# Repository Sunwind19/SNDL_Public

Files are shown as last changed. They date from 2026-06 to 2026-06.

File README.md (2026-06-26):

# SNDL
This is repository for SNDL, a biomimetic robot that is your unique companion for your climate action. When you pick up, SNDL carries! 

## Project Introduction




This is SNDL, a waste collecting beetle-like 6-legged biomimetic robot companion, building a sustainable future through protecting nature closest to our daily life. 

SNDL revolutionize this reality through first-ever innovation inspired by insects’ skeletal structures evolved to survive in harsh terrains. Built over believing “nature already holds the answer to our problem”, SNDL targets to remove all the accumulated trash through collaboration with human. No need to carry heavy wastes and get exhausted over exhausted: you can just hand them in to SNDL and it’ll carry it for you!

By mimicking the Diabolical Ironclad Beetle and the Metallifer Stag Beetle, SNDL plan to restore one mountain ecosystem — one BIOME — proving we aren’t late to save this planet.

## Zine page


## BOM
The key parts here were
-2 PCA boards
-1 ESP Devkit V4
-18 MG90S motors
-20A DC-DC & 2A Dual Buck converter system
-15A & 3A Dual buck system
You can check out the details in BOM (Bill of Materials for SNDL).csv file and get the materials, and follow the schematics.pdf file! Soldering is fine, but I recommend using wago connectors at the beginning since theres high chance motor might burn for beginners. 

## Key CAD file
The most important design choice I made was to mimic insects' exoskeleton into the robot's main frame, so that it can carry a load of waste at once and be perfect companion for your waste-collecting journey. Specifically, SNDL can endure 4900x of its body weight because of its suture! As shown in assembly body.f3z / .step file, this exoskeleton is covered by shell, where body-coxa bracket, bearing bracket, femur and tibia are attached. 

## Firmware
The firmware has inverse kinematics & tripod gait feature.
You can connect your nintendo joycon or any other controller bluepad32 supports!

## Why?
The precious mountains where I once shared precious memories are now covered with waste. Just like scenary in WALL-E. Why? Because we couldn't collect them again unlike when we spreaded them out. Here, I wanted to bring robotic system to foster climate action and prove its not too late.

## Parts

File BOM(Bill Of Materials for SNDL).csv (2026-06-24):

Material name | Number | Total Price for parts(USD) | Link
MG90s 180 degree Motor | 18 | 24.66 | https://www.coupang.com/vp/products/8331026680?itemId=24052890806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
PCA9685 | 2 | 6.44 | https://www.coupang.com/vp/products/1137724853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
ESP32 DevkitC V4 | 1 | 10.24 | https://www.coupang.com/vp/products/8757170787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
18650 Battery (3000mAh, 3.7V) | 4 | 8.44 | https://www.coupang.com/vp/products/5032842187?itemId=25081547722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
18650 Battery Holder (4p) | 1 | 0.56 | https://www.coupang.com/vp/products/7397864403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
DT-830LN Multimeter | 1 | 5.15 | https://www.coupang.com/vp/products/8176825077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
Bulk Capacitor (4700uF, 50V) | 1 | 1.06 | https://www.coupang.com/vp/products/1065561592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
Ceramic Capacitor (0.01uF,50V) | 4 | 0.16 | https://www.coupang.com/vp/products/8540238444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
Fuse for vehicles (3A) | 10 | 1.45 | https://www.coupang.com/vp/products/9497182652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
Fuse for vehicles (15A) | 2 | 0.05 | https://www.coupang.com/vp/products/9195985582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
Fuse holder (5A) | 10 | 7.81 | https://www.coupang.com/vp/products/8511316183?itemId=24637065051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
Fuse holder (20A) | 10 | 9.7 | https://www.coupang.com/vp/products/8511316183?itemId=24637065051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
Flat head screw (M2,10mm) | 36 | 0.95 | https://www.coupang.com/vp/products/6168689383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
Flat head screw (M3,10mm) | 32 | 0.85 | https://www.coupang.com/vp/products/9081428280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
Flat head screw (M3,20mm) | 40 | 1.59 | https://www.coupang.com/vp/products/9081428280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
Hex Nut (M2, 1.5mm) | 36 | 1.19 | https://www.coupang.com/vp/products/8732352217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
Hex Nut (M3, 2.5mm) | 82 | 2.38 | https://www.coupang.com/vp/products/8732352217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
MR84ZZ Bearing | 18 | 3.09 | https://www.coupang.com/vp/products/5448395078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
Standoff (M3,25mm) | 20 | 4.62 | https://www.coupang.com/vp/products/8695499113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
XL4015 DC-DC Stepdown Converter (2A) | 1 | 2.67 | https://www.coupang.com/vp/products/5354288472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
DC-DC Stepdown Converter (300W, 20A) | 1 | 4.62 | https://www.coupang.com/vp/products/9127141798?itemId=26852534394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
221-413 Wago Connector 3p | 50 | 13.87 | https://www.coupang.com/vp/products/7599905141?itemId=7995179122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
221-415 Wago Connector 5p | 5 | 2.28 | https://www.coupang.com/vp/products/8844622739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
Silicon Cable Red & Black 1M (16AWG) | 1 | 0.87 | https://www.coupang.com/vp/products/7225302003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
Silicon Cable Red & Black 1M (22AWG) | 1 | 0.39 | https://www.coupang.com/vp/products/8230958366?itemId=23689081947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
15SQ045 Schottky diode (15A) | 1 | 0.3 | https://www.coupang.com/vp/products/208012195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
F-F Jumper Cable (20cm) | 40 | 0.99 | https://www.coupang.com/vp/products/9066477738?itemId=26624930723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
Total |  | 115.19

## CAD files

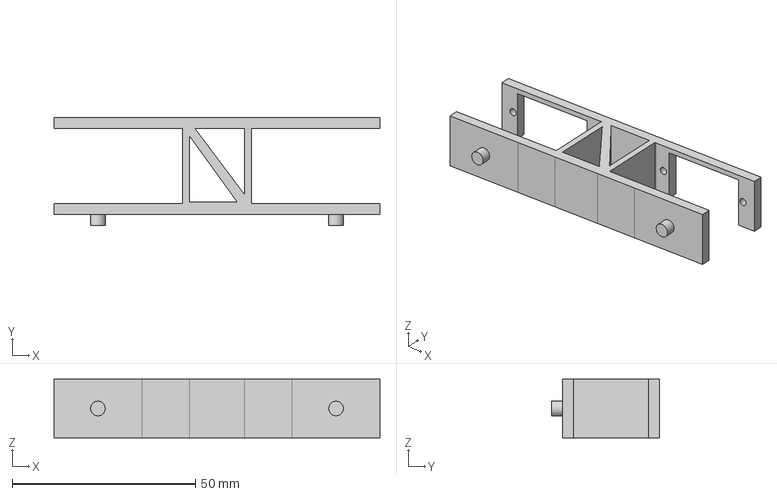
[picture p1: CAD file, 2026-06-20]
CAD files/Femur.step
89.0 x 29.4 x 16.0 mm

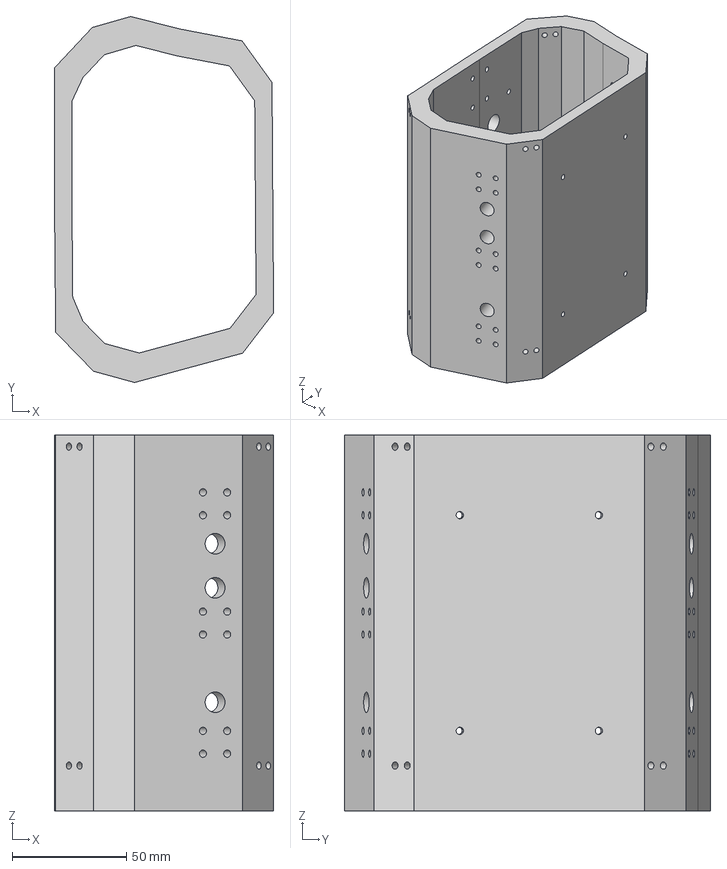
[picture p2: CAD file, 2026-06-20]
CAD files/Exoskeleton Ext.step
95.9 x 160.2 x 164.4 mm

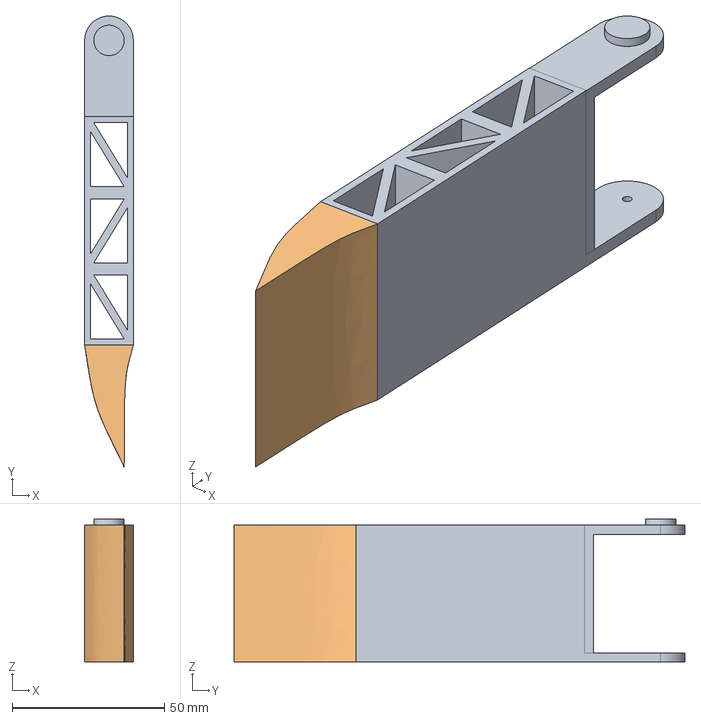
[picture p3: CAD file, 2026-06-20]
CAD files/bearing.step
16.0 x 148.0 x 46.9 mm

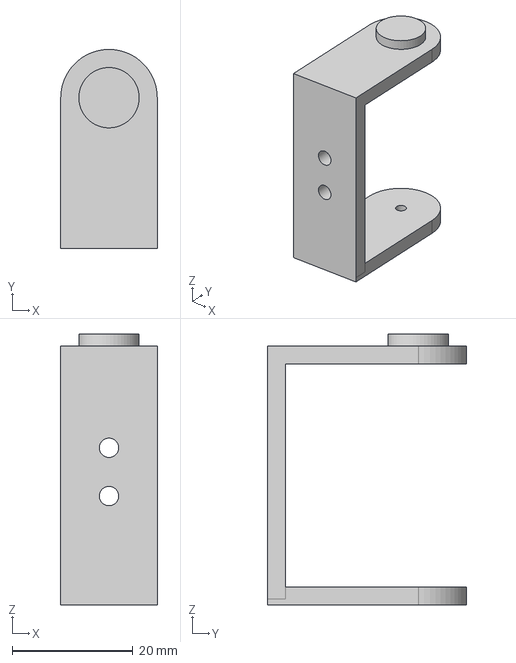
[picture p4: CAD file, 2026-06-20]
CAD files/2nd bearing.step
16.0 x 33.0 x 44.9 mm

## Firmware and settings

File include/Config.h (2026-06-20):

#include "Robot.h"

#include <Arduino.h>
#include "Config.h"
#include "Gait.h"
#include "Hardware.h"
#include "RobotState.h"
#include "StatusLed.h"
#include "ControllerInput.h"

namespace hexabot {

static unsigned long previousFrameTime = 0;
static unsigned long bootStartTime = 0;
static int bootStage = 0;
static bool hardwareInitialized = false;

// ============================================
// SAFE BOOT SEQUENCE (NO BLOCKING I2C IN SETUP)
// ============================================

void setupRobot() {
    Serial.begin(115200);
    delay(500);
    
    Serial.println("\n[BOOT] Starting hexabot initialization...");
    
    // Phase 1: GPIO-only operations (no I2C)
    initializeStatusLed();
    setStatusLed(true);  // Status LED ON during boot
    
    // Do NOT initialize PCA9685 here!
    // Do NOT call Wire.begin() here!
    // Do NOT set Wire.setTimeOut() here!
    
    // Phase 2: Initialize global state
    mode = RobotMode::Waiting;
    resetMotionCommands();
    resetBodyAttitude();
    resetSquatState();
    
    // Phase 3: Wait for power rails to stabilize
    Serial.println("[BOOT] Phase 1: Waiting for power rails to stabilize (3s)...");
    delay(3000);
    
    // Record boot start time for lazy hardware init
    bootStartTime = millis();
    bootStage = 0;
    hardwareInitialized = false;
    previousFrameTime = millis();
    
    Serial.println("[BOOT] Setup complete. Waiting for frame loop...");
}

// ============================================
// LAZY HARDWARE INITIALIZATION (IN UPDATE LOOP)
// ============================================

void updateRobot() {
    const unsigned long now = millis();
    const unsigned long elapsedSinceBoot = now - bootStartTime;
    
    // ========================================
    // STAGE 0: Initialize Wire & PCA9685 (one-time, ~1.5s after boot)
    // ========================================
    if (bootStage == 0 && elapsedSinceBoot > 3500) {
        Serial.println("[BOOT] Stage 0: Initializing I2C and PCA9685...");
        
        // Now safe to initialize I2C and servo drivers
        Wire.begin(21, 22);  // SDA=21, SCL=22 for ESP32
        Wire.setClock(100000);  // 100 kHz I2C clock (stable, not fast)
        
        // Initialize both PCA9685 boards
        initializeServoDrivers();
        
        // Give servo drivers time to settle
        delay(500);
        
        Serial.println("[BOOT] Stage 0: PCA9685 boards initialized");
        bootStage = 1;
        return;  // Skip this frame, try again next frame
    }
    
    // ========================================
    // STAGE 1: Set waiting pose (standing neutral)
    // ========================================
    if (bootStage == 1 && elapsedSinceBoot > 4100) {
        Serial.println("[BOOT] Stage 1: Setting waiting pose...");
        
        fillWaitingPoseTargets();
        interpolateServosToFrameTargets();  // Single smooth interpolation
        
        gaitTick = 0;
        resetTripodPhases();
        
        delay(1000);  // Let servos settle into position
        
        Serial.println("[BOOT] Stage 1: Waiting pose set");
        bootStage = 2;
        return;
    }
    
    // ========================================
    // STAGE 2: Mark hardware as ready, allow walking
    // ========================================
    if (bootStage == 2 && elapsedSinceBoot > 5200) {
        Serial.println("[BOOT] Stage 2: Hardware fully initialized. Ready for motion.");
        
        hardwareInitialized = true;
        mode = RobotMode::Walking;
        bootStage = 3;
        setStatusLed(false);  // Status LED OFF after boot
        
        return;
    }
    
    // ========================================
    // If hardware not ready, wait (no motion)
    // ========================================
    if (!hardwareInitialized) {
        return;  // Still booting, do nothing
    }
    
    // ========================================
    // MAIN LOOP: Only runs after full boot
    // ========================================
    
    if (now - previousFrameTime >= FRAME_TIME_MS) {
        previousFrameTime = now;
        
        // Dummy motion: forward movement only (tripod gait)
        // Remove this and add controller input when ready
        commandedX = 80;    // Forward motion (safe low speed)
        commandedY = 0;     // No strafe
        commandedR = 0;     // No rotation
        rotatingInPlaceMode = false;
        
        // Update gait and servo positions
        switch (mode) {
            case RobotMode::Walking:
                updateTripodGait();
                currentBodyPitch = 0.0f;
                currentBodyRoll = 0.0f;
                break;
                
            case RobotMode::Waiting:
                fillWaitingPoseTargets();
                gaitTick = 0;
                resetBodyAttitude();
                currentTemporaryZOffset = 0.0f;
                break;
                
            default:
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

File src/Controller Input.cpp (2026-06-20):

#include "Controller Input.h"

#include "Config.h"
#include "Gait.h"
#include "RobotState.h"
#include "StatusLed.h"

namespace hexabot {

static Controller* controllers[BP32_MAX_GAMEPADS] = {};

static bool lastYButtonState = false;
static bool lastXButtonState = false;
static bool lastAButtonState = false;
static bool lastDpadUpState = false;
static bool lastDpadDownState = false;
static bool lastDpadLeftState = false;
static bool lastDpadRightState = false;

static float mapFloat(float value, float inMin, float inMax, float outMin, float outMax) {
    return (value - inMin) * (outMax - outMin) / (inMax - inMin) + outMin;
}

static int axisToCommand(int axis, bool invert = false) {
    int value = static_cast<int>(roundf(mapFloat(static_cast<float>(axis), -512.0f, 511.0f, -127.0f, 127.0f)));
    value = constrain(value, -127, 127);
    return invert ? -value : value;
}

static float axisToAngle(int axis, float minAngle, float maxAngle) {
    return mapFloat(static_cast<float>(axis), -512.0f, 511.0f, minAngle, maxAngle);
}

static void onConnectedController(Controller* controller) {
    Serial.println("Controller connected callback fired.");
    Serial.printf("  Connected: %s\n", controller->isConnected() ? "true" : "false");
    Serial.printf("  Gamepad: %s\n", controller->isGamepad() ? "true" : "false");

    for (uint8_t i = 0; i < BP32_MAX_GAMEPADS; ++i) {
        if (controllers[i] == nullptr) {
            controllers[i] = controller;
            Serial.printf("  Assigned controller to slot %u.\n", i);
            return;
        }
    }

    Serial.println("  No free controller slots available.");
}

static void onDisconnectedController(Controller* controller) {
    Serial.println("Controller disconnected. Bluepad32 will keep trying to reconnect known devices.");

    for (uint8_t i = 0; i < BP32_MAX_GAMEPADS; ++i) {
        if (controllers[i] == controller) {
            controllers[i] = nullptr;
        }
    }
}

void initializeControllerInput() {
    BP32.setup(&onConnectedController, &onDisconnectedController);
    // Uncomment while testing if you need to erase all remembered Bluetooth pairings.
    // BP32.forgetBluetoothKeys();
    BP32.enableVirtualDevice(false);
}

void updateControllerInput() {
    BP32.update();
}

Controller* getActiveController() {
    for (uint8_t i = 0; i < BP32_MAX_GAMEPADS; ++i) {
        Controller* controller = controllers[i];
        if (controller != nullptr && controller->isConnected() && controller->isGamepad()) {
            return controller;
        }
    }
    return nullptr;
}

void handleModeButtons(Controller* controller) {
    if (controller == nullptr) {
        lastYButtonState = false;
        lastXButtonState = false;
        return;
    }

    const bool currentY = controller->y();
    if (currentY && !lastYButtonState) {
        if (mode == RobotMode::Waiting) {
            mode = RobotMode::Walking;
            gaitTick = 0;
            resetTripodPhases();
            Serial.println("Mode: WALKING. Robot is rising into its home pose.");
        } else if (mode == RobotMode::Walking || mode == RobotMode::Following) {
            mode = RobotMode::Waiting;
            gaitTick = 0;
            resetSquatState();
            Serial.println("Mode: WAITING. Robot is returning to the safe waiting pose.");
        }
        quickFlashLed();
    }
    lastYButtonState = currentY;

    const bool currentX = controller->x();
    if (currentX && !lastXButtonState) {
        if (mode == RobotMode::Walking) {
            mode = RobotMode::Following;
            gaitTick = 0;
            resetBodyAttitude();
            resetSquatState();
            Serial.println("Mode: FOLLOWING. Body attitude follows the right joystick.");
            quickFlashLed();
        } else if (mode == RobotMode::Following) {
            mode = RobotMode::Walking;
            gaitTick = 0;
            resetBodyAttitude();
            resetSquatState();
            Serial.println("Mode: WALKING. Robot is returning to gait control.");
            quickFlashLed();
        }
    }
    lastXButtonState = currentX;
}

void handleDpadAdjustments(Controller* controller) {
    if (controller == nullptr) {
        lastDpadUpState = false;
        lastDpadDownState = false;
        lastDpadLeftState = false;
        lastDpadRightState = false;
        return;
    }

    const uint8_t dpad = controller->dpad();
    const bool dpadUp = (dpad & DPAD_UP) != 0;
    const bool dpadDown = (dpad & DPAD_DOWN) != 0;
    const bool dpadLeft = (dpad & DPAD_LEFT) != 0;
    const bool dpadRight = (dpad & DPAD_RIGHT) != 0;

    if (dpadUp && !lastDpadUpState) {
        globalSpeedMultiplier = min(globalSpeedMultiplier + SPEED_STEP, MAX_SPEED_MULTIPLIER);
        Serial.printf("Speed multiplier: %.1f\n", globalSpeedMultiplier);
        quickFlashLed();
    } else if (dpadDown && !lastDpadDownState) {
        globalSpeedMultiplier = max(globalSpeedMultiplier - SPEED_STEP, MIN_SPEED_MULTIPLIER);
        Serial.printf("Speed multiplier: %.1f\n", globalSpeedMultiplier);
        quickFlashLed();
    }

    if (dpadLeft && !lastDpadLeftState) {
        currentBodyZOffset = max(currentBodyZOffset - BODY_HEIGHT_STEP_MM, MIN_BODY_HEIGHT_OFFSET_MM);
        Serial.printf("Body height Z offset: %.1f mm\n", currentBodyZOffset);
        quickFlashLed();
    } else if (dpadRight && !lastDpadRightState) {
        currentBodyZOffset = min(currentBodyZOffset + BODY_HEIGHT_STEP_MM, MAX_BODY_HEIGHT_OFFSET_MM);
        Serial.printf("Body height Z offset: %.1f mm\n", currentBodyZOffset);
        quickFlashLed();
    }

    lastDpadUpState = dpadUp;
    lastDpadDownState = dpadDown;
    lastDpadLeftState = dpadLeft;
    lastDpadRightState = dpadRight;
}

static void updateSquatState() {
    if (squatState == SquatState::Idle) {
        return;
    }

    const unsigned long elapsedMs = millis() - squatStartTime;
    const float phaseDurationMs = SQUAT_DURATION_MS / 2.0f;

    if (squatState == SquatState::Down) {
        const float progress = min(1.0f, static_cast<float>(elapsedMs) / phaseDurationMs);
        currentTemporaryZOffset = targetTemporaryZOffset * progress;

        if (progress >= 1.0f) {
            currentTemporaryZOffset = targetTemporaryZOffset;
            squatState = SquatState::Up;
            squatStartTime = millis();
            Serial.println("Squat: moving up.");
        }
    } else if (squatState == SquatState::Up) {
        const float progress = min(1.0f, static_cast<float>(elapsedMs) / phaseDurationMs);
        currentTemporaryZOffset = targetTemporaryZOffset + (0.0f - targetTemporaryZOffset) * progress;

        if (progress >= 1.0f) {
            resetSquatState();
            Serial.println("Squat: finished.");
        }
    }
}
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

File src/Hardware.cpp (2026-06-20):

// Hardware.cpp - Simplified PCA9685 initialization
// Put this in your src/Hardware.cpp or adapt to your existing code

#include "Hardware.h"
#include <Wire.h>
#include <Arduino.h>

namespace hexabot {

// PCA9685 I2C addresses (example: both on address 0x40)
static const uint8_t PCA9685_ADDR_LEFT = 0x40;    // Left leg/arm board
static const uint8_t PCA9685_ADDR_RIGHT = 0x41;   // Right leg/tong board

// ============================================
// PCA9685 Register definitions
// ============================================
#define PCA9685_MODE1 0x00
#define PCA9685_MODE2 0x01
#define PCA9685_PRESCALE 0xFE
#define PCA9685_LED0_ON_L 0x06
#define PCA9685_LED0_ON_H 0x07
#define PCA9685_LED0_OFF_L 0x08
#define PCA9685_LED0_OFF_H 0x09

#define PCA9685_MODE1_SLEEP (1 << 4)
#define PCA9685_MODE1_AI (1 << 5)     // Auto-increment
#define PCA9685_MODE1_RESTART (1 << 7)

static void pca9685_write_register(uint8_t addr, uint8_t reg, uint8_t val) {
    Wire.beginTransmission(addr);
    Wire.write(reg);
    Wire.write(val);
    Wire.endTransmission();
}

static uint8_t pca9685_read_register(uint8_t addr, uint8_t reg) {
    Wire.beginTransmission(addr);
    Wire.write(reg);
    Wire.endTransmission(false);  // Don't release bus
    
    Wire.requestFrom((int)addr, 1);
    if (Wire.available()) {
        return Wire.read();
    }
    return 0xFF;
}

void initializeServoDrivers() {
    Serial.println("[HW] Initializing PCA9685 boards...");
    
    // Initialize left board (legs)
    initializePCA9685(PCA9685_ADDR_LEFT, "Left");
    
    // Initialize right board (more servos)
    initializePCA9685(PCA9685_ADDR_RIGHT, "Right");
    
    Serial.println("[HW] PCA9685 initialization complete");
}

void initializePCA9685(uint8_t addr, const char* name) {
    Serial.printf("[HW] Initializing PCA9685 (%s) at 0x%02X\n", name, addr);
    
    // Step 1: Exit sleep mode
    uint8_t mode1 = pca9685_read_register(addr, PCA9685_MODE1);
    mode1 &= ~PCA9685_MODE1_SLEEP;  // Clear sleep bit
    pca9685_write_register(addr, PCA9685_MODE1, mode1 | PCA9685_MODE1_AI);
    
    // Step 2: Set prescaler for 50Hz (servo standard frequency)
    // Prescaler = (25MHz / (4096 * 50Hz)) - 1 = 121 (0x79)
    pca9685_write_register(addr, PCA9685_PRESCALE, 121);
    
    // Step 3: Set all channels to 0% (all servos neutral at startup)
    // Faster than setting 16 channels individually
    Wire.beginTransmission(addr);
    Wire.write(PCA9685_LED0_ON_L);
    Wire.write(0x00);      // ON_L = 0
    Wire.write(0x00);      // ON_H = 0
    Wire.write(0x00);      // OFF_L = 0
    Wire.write(0x10);      // OFF_H = 0x10 (center position for MG90S: 1500µs)
    Wire.endTransmission();
    
    delay(50);  // Small delay for register write to settle
    
    Serial.printf("[HW] %s board ready (50Hz PWM, neutral position)\n", name);
}

void setServoAngle(uint8_t boardAddr, uint8_t channel, float angleDegrees) {
    // Map angle to PWM pulse width (MG90S: 500-2500µs for -90 to +90°)
    // Center: 1500µs = 0°
    // Formula: pulse = 1500 + (angle * 1000/180)
    
    float pulse_ms = 1.5f + (angleDegrees * 10.0f / 180.0f);
    pulse_ms = constrain(pulse_ms, 1.0f, 2.0f);  // Clamp to safe range
    
    // Convert to PCA9685 tick count (4096 ticks per 20ms period = 50Hz)
    uint16_t ticks = (uint16_t)(pulse_ms * 4096.0f / 20.0f);
    ticks = constrain(ticks, 200, 500);  // Safe limits (1-2.5ms)
    
    // Write to channel
    uint8_t on_l = 0;
    uint8_t on_h = 0;
    uint8_t off_l = ticks & 0xFF;
    uint8_t off_h = (ticks >> 8) & 0x0F;
    
    uint8_t reg = PCA9685_LED0_ON_L + (channel * 4);
    
    Wire.beginTransmission(boardAddr);
    Wire.write(reg);
    Wire.write(on_l);
    Wire.write(on_h);
    Wire.write(off_l);
    Wire.write(off_h);
    Wire.endTransmission();
}

} 
 // namespace hexabot
 /*
#include <Wire.h>
#include "RobotState.h"
#include "Hardware.h"

namespace hexabot {

Adafruit_PWMServoDriver pwmLeft(PCA9685_ADDRESS_LEFT);
Adafruit_PWMServoDriver pwmRight(PCA9685_ADDRESS_RIGHT);

// Right side: 0=front right, 1=middle right, 2=back right.
static ServoConfig frontRightCoxa  = { &pwmRight, 15, "front right coxa",  COXA_CAL[FRONT_RIGHT], false };
static ServoConfig frontRightFemur = { &pwmRight, 14, "front right femur", FEMUR_CAL[FRONT_RIGHT], false };
static ServoConfig frontRightTibia = { &pwmRight, 13, "front right tibia", TIBIA_CAL[FRONT_RIGHT], false };

static ServoConfig middleRightCoxa  = { &pwmRight,  4, "middle right coxa",  COXA_CAL[MIDDLE_RIGHT], false };
static ServoConfig middleRightFemur = { &pwmRight, 5, "middle right femur", FEMUR_CAL[MIDDLE_RIGHT], false };
static ServoConfig middleRightTibia = { &pwmRight, 6, "middle right tibia", TIBIA_CAL[MIDDLE_RIGHT], false };
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

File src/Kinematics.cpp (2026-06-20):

#include "Kinematics.h"

#include "Hardware.h"
#include "RobotState.h"

namespace hexabot {

static float clampFloat(float value, float minValue, float maxValue) {
    if (value < minValue) return minValue;
    if (value > maxValue) return maxValue;
    return value;
}

static void keepCurrentServoAngles(uint8_t legNumber) {
    const uint8_t base = legNumber * SERVOS_PER_LEG;
    frameTargetCoxa[legNumber] = allServos[base + 0].currentAngleDeg;
    frameTargetFemur[legNumber] = allServos[base + 1].currentAngleDeg;
    frameTargetTibia[legNumber] = allServos[base + 2].currentAngleDeg;
}

static float compensateCoxaMounting(uint8_t legNumber, float coxaAngleDeg) {
    switch (legNumber) {
        case FRONT_RIGHT:
            return coxaAngleDeg + 45.0f;
        case MIDDLE_RIGHT:
            return coxaAngleDeg + 90.0f;
        case BACK_RIGHT:
            return coxaAngleDeg + 135.0f;
        case BACK_LEFT:
            return (coxaAngleDeg < 0.0f) ? coxaAngleDeg + 225.0f : coxaAngleDeg - 135.0f;
        case MIDDLE_LEFT:
            return (coxaAngleDeg < 0.0f) ? coxaAngleDeg + 270.0f : coxaAngleDeg - 90.0f;
        case FRONT_LEFT:
            return (coxaAngleDeg < 0.0f) ? coxaAngleDeg + 315.0f : coxaAngleDeg - 45.0f;
        default:
            return coxaAngleDeg;
    }
}

void computeLegIK(uint8_t legNumber, float x, float y, float z) {
    if (legNumber >= LEG_COUNT) {
        return;
    }

    const float l0 = sqrtf((x * x) + (y * y)) - COXA_LENGTH_MM;
    const float l3 = sqrtf((l0 * l0) + (z * z));

    const float maxReach = FEMUR_LENGTH_MM + TIBIA_LENGTH_MM + 0.1f;
    const float minReach = fabsf(TIBIA_LENGTH_MM - FEMUR_LENGTH_MM) - 0.1f;

    if (l3 >= maxReach || l3 <= minReach || l3 <= 0.001f) {
        keepCurrentServoAngles(legNumber);
        return;
    }

    const float tibiaCos = clampFloat(
        ((FEMUR_LENGTH_MM * FEMUR_LENGTH_MM) + (TIBIA_LENGTH_MM * TIBIA_LENGTH_MM) - (l3 * l3)) /
            (2.0f * FEMUR_LENGTH_MM * TIBIA_LENGTH_MM),
        -1.0f,
        1.0f
    );
    const float phiTibia = acosf(tibiaCos);
    const float thetaTibia = (phiTibia * RAD_TO_DEG) - 40.0f;

    const float gammaFemur = atan2f(z, l0);
    const float femurCos = clampFloat(
        ((FEMUR_LENGTH_MM * FEMUR_LENGTH_MM) + (l3 * l3) - (TIBIA_LENGTH_MM * TIBIA_LENGTH_MM)) /
            (2.0f * FEMUR_LENGTH_MM * l3),
        -1.0f,
        1.0f
    );
    const float phiFemur = acosf(femurCos);
    const float thetaFemur = ((phiFemur + gammaFemur) * RAD_TO_DEG) + 90.0f;

    const float rawCoxa = atan2f(x, y) * RAD_TO_DEG;
    const float thetaCoxa = compensateCoxaMounting(legNumber, rawCoxa);

    frameTargetCoxa[legNumber] = thetaCoxa;
    frameTargetFemur[legNumber] = thetaFemur;
    frameTargetTibia[legNumber] = thetaTibia;
}

}  // namespace hexabot

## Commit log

2026-06-24 Update BOM with new material entries
    [BOM(Bill Of Materials for SNDL).csv]
2026-06-24 Create Assembly body_Fin.f3z
2026-06-24 Create Assembly body.step
